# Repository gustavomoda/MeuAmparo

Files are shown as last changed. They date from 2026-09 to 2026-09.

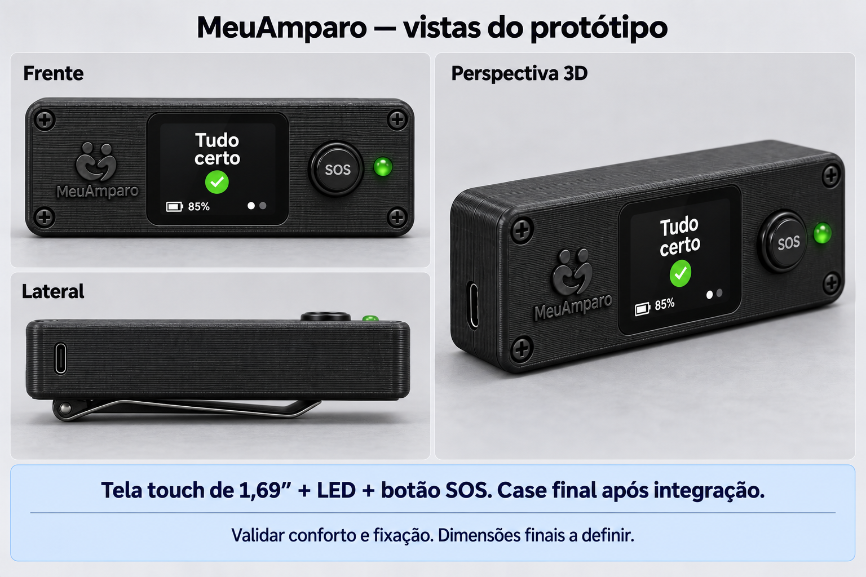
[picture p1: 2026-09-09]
docs/projeto/03-hardware/renders/touch_vistas.png

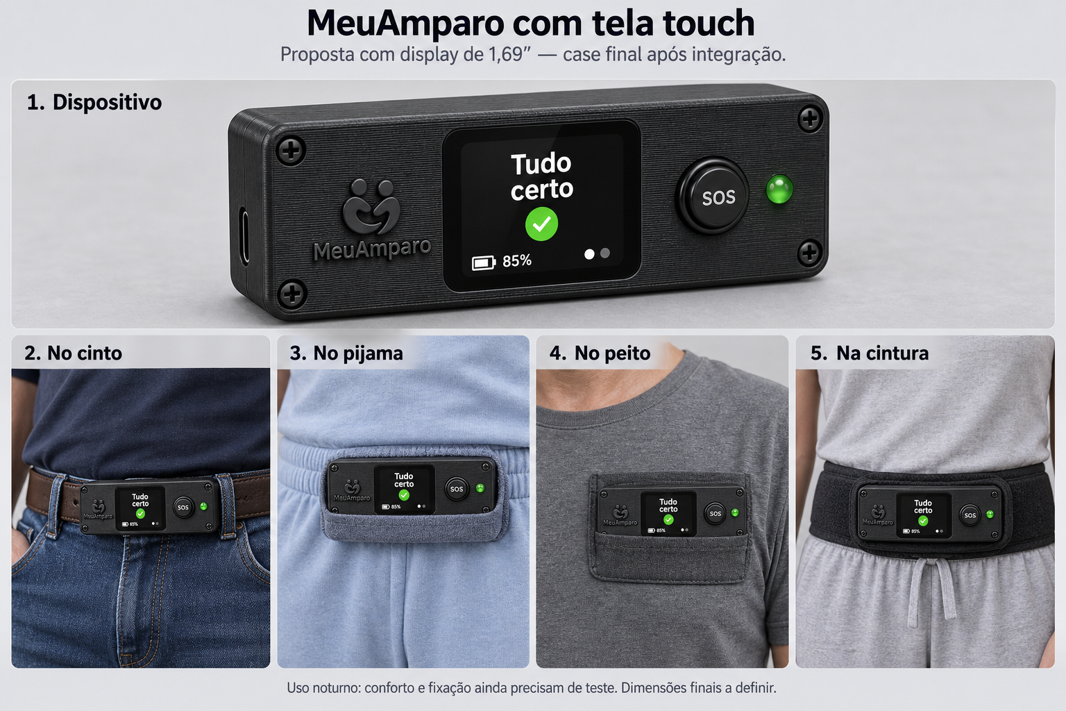
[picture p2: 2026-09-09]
docs/projeto/03-hardware/renders/touch_169_dispositivo_e_fixacoes.png

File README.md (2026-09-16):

MeuAmparo

# MeuAmparo

Dispositivo vestível de baixo custo para pessoas idosas: detecta queda, aceita pedido manual de
ajuda pelo botão e avisa o cuidador com a localização, inclusive quando a pessoa sai de uma área
segura.

Projeto de extensão da disciplina Programação de Microcontroladores (ARA4710), Estácio Ribeirão
Preto, semestre 2026.2. O desenvolvimento e os testes acontecem em simulação, no Wokwi, como o
roteiro da disciplina prevê; não haverá montagem física neste semestre.

O acompanhamento das tarefas fica no [quadro do projeto no GitHub](https://github.com/users/gustavomoda/projects/2):
cada entrega da disciplina é um marco, cada tarefa tem prazo, responsável e critério de pronto.

## Estado atual

Início do desenvolvimento, em 16/09/2026. O que existe hoje:

| Parte | Estado |
| --- | --- |
| Documentação da disciplina | Roteiro 1 entregue; Roteiro 2 em rascunho para 23/09; canvas apresentado |
| Instituição parceira | levantamento de 14 entidades; nenhuma contatada ainda |
| Hardware | case paramétrico em OpenSCAD, com STL de base e tampa, nunca conferido com a placa |
| Identidade visual | marca e ícone em PNG e SVG |
| `core/` | só a magnitude de aceleração, com teste de host passando |
| `firmware/` | projeto ESP-IDF mínimo, que pisca um LED |
| `simulator/` | diagrama Wokwi com ESP32-S3 e LED, rodando o firmware mínimo |
| Backend e painel | não iniciados |

Nada foi montado nem medido em placa física, e não vai ser neste semestre. Os números que aparecem
na documentação são metas e estimativas, não resultados.

## Estrutura

```text
docs/material-disciplina/   material recebido da Estácio, não editar
docs/projeto/               entregas, instituições, hardware e identidade visual (tem um README)
src/meuamparo/              código: core, firmware, simulador e testes
.agents/                    instruções para agentes de IA que trabalham no repositório
```

O código fica em `src/meuamparo/`, separado em quatro pastas com uma fronteira rígida:

```text
core/       algoritmos em C puro. Não sabe que ESP32 existe
firmware/   ESP-IDF. Só o que roda na placa
simulator/  Wokwi, custom chips e traces. Nada daqui vai para a placa
test/       testes de host, rodam sem ESP-IDF instalado
```

O motivo da separação está em [`src/meuamparo/README.md`](src/meuamparo/README.md). Resumindo: a meta
de detectar 90% das quedas só se mede rodando o algoritmo contra centenas de traces, e isso precisa
compilar em segundos no notebook, sem placa.

## Rodando

Os testes do core precisam só de um compilador C11. Firmware e simulação precisam do ESP-IDF e do
`wokwi-cli`, que o `make setup` instala.

```sh
cd src/meuamparo
make help      # lista os alvos
make test      # compila e roda os testes do core, sem ESP-IDF
make setup     # instala ESP-IDF e wokwi-cli, pulando o que já existe
make firmware  # compila o firmware (com o export.sh do ESP-IDF carregado)
make sim       # roda o firmware no Wokwi
```

## Arquitetura

A placa de referência é a Waveshare ESP32-S3-SIM7670G-4G, que junta o ESP32-S3, o modem 4G e o GNSS.
Em volta dela: sensor inercial MPU6050, bateria 18650, botão de pânico, buzzer e LED. Firmware em C
com ESP-IDF. Backend e painel web de alertas ainda sem stack definida.

A simulação no Wokwi cobre o ESP32-S3, o MPU6050, o botão, o buzzer e o LED. O 4G e o GNSS não
existem no simulador e serão representados de outra forma, por exemplo pelo Wi-Fi simulado.

## Metas

Detectar pelo menos 90% das quedas simuladas, menos de um alarme falso por dia, alerta de saída da
área segura em até dois minutos, autonomia mínima de oito horas, configuração independente em menos
de 15 minutos e avaliação da instituição parceira de pelo menos 4/5.

São critérios definidos no planejamento. Nenhum foi medido, e alguns (autonomia, alarmes falsos por
dia, configuração pela equipe) dependem de hardware que não vai existir neste semestre; a forma de
avaliá-los em simulação ainda está sendo decidida.

## Pendências

- **Simulador**: o Wokwi não é software livre, que é o que o roteiro da disciplina cita. Falta
  confirmar com o professor.
- **Documentos antigos**: o canvas e o Markdown de compras ainda citam a LilyGO T-A7670G R2, opção
  anterior à Waveshare, e as imagens conceituais em `docs/projeto/03-hardware/renders/` mostram uma
  tela touch que não faz parte do projeto.
- **Divisão do trabalho**: as frentes (instituição, firmware, backend, documentação) ainda não têm
  responsável nominal.
- **Instituição parceira**: em prospecção. Casa do Vovô, Lar Padre Euclides e Lar do Vovô Albano são
  as candidatas. Nenhuma parceria firmada.
- **Dataset de queda**: SisFall e FallAllD são os candidatos, licença e formato a conferir.

## Grupo

- Luis Gustavo Moda
- Isabelly Vitoria

Orientação: Prof. Omar Sacilotto Donaires.

## Licença

O código e os materiais autorais do MeuAmparo são disponibilizados sob a
[GNU General Public License, versão 3](LICENSE) (`GPL-3.0-only`).

Materiais da disciplina, dependências e outros conteúdos de terceiros mantêm suas próprias licenças.

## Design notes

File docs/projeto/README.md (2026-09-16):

# Documentos do MeuAmparo

Aqui fica tudo o que o grupo escreveu para a disciplina e para o projeto. O material que veio da
Estácio, como aulas, modelos e edital, está em [`docs/material-disciplina/`](../material-disciplina).
Se você ainda não sabe o que é o MeuAmparo, leia antes o [README principal](../../README.md).

## Se você só precisa da entrega

Os PDFs que vão para a SAVA ficam direto em `01-entregas/`, para quem só quer ler. A disciplina
aceita só PDF, um por grupo.

O texto dos roteiros é escrito em Markdown, em `md/`, e é dele que saem o Word e o PDF. A geração
automática ainda está sendo montada; até ela ficar pronta, quem mexer no Markdown precisa levar a
mudança para o `.docx` em `docx/`. Os Canvas são a exceção: eles seguem o modelo do professor e
continuam sendo editados direto no Word.

- Roteiro 1, diagnóstico e teorização: prazo em 09/09, PDF gerado.
- Roteiro 2, planejamento: prazo em 23/09, ainda em rascunho e sem PDF.
- Canvas do projeto e Canvas de apresentação: usados nos seminários. Só o de apresentação tem PDF.

## Datas que importam

| Data | O que acontece | Pontos |
| --- | --- | --- |
| 09/set | Entrega do diagnóstico e teorização | 2,0 |
| 16/set | Seminário de planejamento | — |
| 21/set | Prazo de submissão do III EPEI | — |
| 23/set | Entrega do planejamento | 1,0 |
| 28/out | Seminário de desenvolvimento | — |
| 25/nov | Entrega final e seminário de avaliação | 7,0 |

Para passar, a nota precisa ser 6,0 ou mais, com pelo menos 75% de frequência. Essas datas são as
do calendário atualizado na Aula 04. O Canvas ainda mostra as da Aula 01, que foram adiadas: o
diagnóstico era 02/09 e o seminário de desenvolvimento, 21/10.

## Onde está cada coisa

```text
01-entregas/            os PDFs entregues na SAVA
  md/                   texto dos roteiros, a fonte de onde sai o resto
  docx/                 versão em Word
  figuras/              imagens usadas nas entregas, como o Gantt
02-parte-interessada/   14 instituições de Ribeirão Preto e o Conselho do Idoso, com roteiro de ligação
03-hardware/            cotação, projeto do case e onde usar o dispositivo no corpo
  case/                 modelo em OpenSCAD e os STL da base e da tampa
  renders/              imagens conceituais do case e das formas de prender
04-identidade-visual/   marca e ícone, em PNG e SVG
```

Nas pastas 02 e 03, o `.docx` e o `.md` de um mesmo documento ainda ficam lado a lado e não se
atualizam sozinhos. Quem mexer em um precisa levar a mudança para o outro, senão os dois começam a
contar histórias diferentes, o que já aconteceu neste projeto.

As imagens de `03-hardware/renders/` são estudos de aparência. Algumas mostram uma tela touch que
não faz parte da arquitetura nem da cotação.

## O que ainda não está resolvido

A instituição parceira ainda não existe. Casa do Vovô, Lar Padre Euclides e Lar do Vovô Albano são
as candidatas mais fortes, mas até agora nenhuma foi visitada e nenhum acordo foi fechado. O
planejamento depende dessa conversa: sem ela, não há como dizer como a equipe da instituição vai
participar.

A placa de referência é a Waveshare ESP32-S3-SIM7670G. Ela usa o mesmo chip, o ESP32-S3, que o
código e o simulador já usam, e o case foi desenhado para ela. Só que ela não vai ser comprada neste
semestre: não dá tempo de receber, montar e testar até novembro. Uma unidade completa custaria entre
R$ 597 e R$ 622, pela estimativa de setembro de 2026. O case partiu das medidas do catálogo e nunca
foi conferido com a placa. Parte dos documentos ainda cita a LilyGO T-A7670G R2, a opção anterior.

Pelo roteiro da disciplina, o sistema é desenvolvido e testado em simulação, e a montagem física só
entra se houver recursos. Aqui ela não vai entrar: todo o desenvolvimento e os testes são no Wokwi. Só que o roteiro pede software livre, e
o Wokwi não é; essa escolha ainda precisa ser justificada ou combinada com o professor.

O cronograma divide o trabalho por frente (instituição, hardware, firmware e documentação), mas
ainda não diz quem cuida de cada uma.

E vale lembrar que nada foi montado nem medido até agora. Números como os 90% de detecção de queda
são metas, não resultados.

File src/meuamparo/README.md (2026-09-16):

# MeuAmparo — firmware e simulador

Dispositivo vestível de baixo custo para pessoas idosas: detecta queda, aceita pedido manual de
ajuda pelo botão e avisa o cuidador com a localização, inclusive quando a pessoa sai de uma área
segura.

Disciplina Programação de Microcontroladores (ARA4710), Estácio Ribeirão Preto, 2026.2.
Grupo: Luis Gustavo Moda e Isabelly Vitoria. Orientação: Prof. Omar Sacilotto Donaires.

## Estrutura

```
core/         algoritmos em C puro. Não sabe que ESP32 existe.
firmware/     ESP-IDF. Só entra aqui o que roda na placa física.
simulator/    Wokwi, custom chips, traces e ferramentas. Nada daqui vai para a placa.
test/         testes de host do core, rodam no Mac sem ESP-IDF instalado.
```

A fronteira entre as três pastas é a regra mais importante do repositório. `core/` não inclui
nenhum header do ESP-IDF. `firmware/` não contém trace, mock nem cenário. `simulator/` pode
depender de qualquer coisa, porque não vai para produção.

## Como rodar

```
make setup      instala ESP-IDF e wokwi-cli, pulando o que já existe
make test       compila e roda os testes de host do core
make firmware   compila o firmware ESP-IDF
make sim        roda a demo no Wokwi headless sobre o binário compilado
make clean      apaga build/ e firmware/build/
```

`make test` não depende de nada disso. Precisa de um compilador C11 e mais nada, que é o motivo
de ele rodar igual no Mac, no Windows do laboratório e num CI sem toolchain de embarcado.

Os outros alvos precisam do ESP-IDF. `make setup` clona a v5.5.5 em `~/esp/esp-idf`, instala a
toolchain do esp32s3 em `~/.espressif` e o `wokwi-cli` pelo npm. Cada etapa confere antes de
baixar, então repetir o comando custa segundos em vez de vários GB. Serve para conferir uma
máquina nova sem medo de refazer download.

Feito o setup, falta carregar o ambiente na shell uma vez por sessão:

```
. ~/esp/esp-idf/export.sh
export WOKWI_CLI_TOKEN=...   # token de CI, em https://wokwi.com/dashboard/ci
```

`make sim` compila antes de rodar e falha se a linha `led=1` não aparecer no serial em 10
segundos. O LED piscando no navegador é o que se vê na apresentação; o critério de verificação
é essa linha no log.

## A demo do LED

`firmware/main/main.c` pisca o GPIO2 a cada meio segundo e imprime o estado. Não lê sensor, não
chama o `core/` e não envia alerta nenhum. Existe para fechar a cadeia do passo 4 antes de haver
lógica dentro dela: o ESP-IDF compila, o binário sobe no Wokwi, o pino responde. Quando o detector
de queda entrar, esse LED vira o indicador de alerta.

O circuito fica em `simulator/wokwi/diagram.json`: devkit ESP32-S3, LED e resistor de 330 Ω.

## Por que separar assim

A meta documentada é detectar pelo menos 90% das quedas simuladas com menos de um alarme falso
por dia. Isso não se mede apertando botão no simulador: mede-se rodando o algoritmo contra
centenas de traces de acelerômetro e contando acertos. Para isso o algoritmo precisa compilar no
Mac, em segundos, sem placa e sem toolchain de embarcado. Daí o `core/`.

O firmware fica fino de propósito: lê o MPU6050, lê o GNSS, chama o core, obedece ao que o core
decidir. Se a lógica de queda vivesse dentro de uma task do FreeRTOS, cada ajuste de limiar
custaria um ciclo de compilar, gravar e derrubar o protótipo de novo.

## Decisões, e por quê

### PICSimLab ficou de fora

PICSimLab simula PIC16/18, AVR e STM32. Não simula ESP32, então não roda uma linha do firmware
deste projeto. Também não tem peça para MPU6050, GNSS ou modem: sensor de queda e GPS virariam
texto digitado num terminal virtual.

Ele aparece na Aula 04 como leitura do Módulo 2 do conteúdo digital, junto com MPLAB e CCS C. É
bibliografia da disciplina, não exigência do projeto. A Aula 03 lista o ESP32 entre as famílias
de microcontrolador estudadas, ao lado de PIC, AVR e ARM.

### Wokwi como bancada visual

O Wokwi roda o binário do ESP-IDF de verdade, não uma reimplementação. Tem ESP32-S3, MPU6050,
botão, LED e buzzer como peças prontas. Roda no navegador, o que resolve Mac, Windows e a máquina
do laboratório com a mesma URL e nenhuma instalação. A extensão do VS Code roda local nos dois
sistemas, mas pede chave de licença.

### O modem 4G não é simulado. O transporte é trocado

Nenhum simulador tem modelo de SIM7670 ou A7670. Em vez de escrever um chip falso que responde
comandos AT, o firmware conversa com uma interface de transporte que tem duas implementações: no
Wokwi sai pelo Wi-Fi virtual, que dá internet real ao ESP32 simulado; na placa sai pelo modem.
O backend recebe a mesma requisição nos dois casos e não precisa saber a diferença.

Isso troca um custom chip complicado por uma interface de três funções. O preço é honesto: o
caminho do modem continua sem cobertura de teste até a placa chegar.

### GNSS precisa de custom chip

Aqui não tem atalho. O Wokwi não tem GPS na biblioteca, então o jeito é escrever um custom chip
que cospe sentenças NMEA de uma rota gravada. É o que permite a demo rodar sozinha: a pessoa
caminha, sai da área segura, o alerta dispara sem ninguém arrastar slider.

### O que simulador nenhum prova

Autonomia de oito horas só sai medindo a placa com a bateria real. Conforto e fixação dependem
das pessoas da instituição parceira. Alarme falso em uso cotidiano depende de rotina real, não de
trace de laboratório. O simulador cobre lógica e demonstração, e é isso.

## Plano

Cada passo tem um critério de verificação. Passo sem critério verificável não conta como pronto.

1. Esqueleto e `core/` compilando isolado. Verifica: `make test` passa no Mac, sem ESP-IDF.
2. Detector de queda e replayer de trace. Verifica: taxa de detecção e falsos positivos impressos
   como número, medidos contra dataset público.
3. Geofence e máquina de estados. Verifica: teste dispara alerta ao cruzar o raio, e uma vez só.
4. Firmware ESP-IDF com transporte Wi-Fi. Verifica: compila, sobe no Wokwi, alerta sai no log.
5. Custom chips do simulador (GNSS e replay do MPU). Verifica: cenário roda do play até o alerta
   sem interação, com LED e buzzer disparando.
6. Backend mínimo e painel com mapa. Verifica: alerta saído do Wokwi aparece no painel.
7. Seeder de dados sintéticos. Verifica: painel com histórico e vários dispositivos.
8. Documentos da disciplina. Verifica: coerência entre Word, Markdown e Canvas.

## Pendências

- A placa é a Waveshare ESP32-S3-SIM7670G. O Wokwi não tem peça para o modem 4G nem para o GNSS,
  então essas partes precisam ser representadas de outro jeito na simulação.
- Dataset de queda: SisFall e FallAllD são os candidatos. Conferir licença e formato antes de usar.
- Licença do Wokwi para a extensão do VS Code. A versão web resolve a apresentação.

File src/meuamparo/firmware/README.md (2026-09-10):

# firmware

Só entra aqui código que roda no ESP32-S3. Se não vai para a placa, o lugar é `../simulator/`.

Responsabilidade: ler o MPU6050 por I2C, ler o GNSS por UART, alimentar o `core/` com esses dados
e executar o que o core decidir (acender LED, tocar buzzer, enviar alerta). A lógica de queda e de
área segura não mora aqui, mora em `../core/`.

O envio do alerta passa por uma interface de transporte com duas implementações: Wi-Fi, usada no
Wokwi, e modem 4G, usada na placa. O resto do firmware não sabe qual das duas está ativa.

Nenhum trace, mock ou cenário de teste entra nesta pasta.

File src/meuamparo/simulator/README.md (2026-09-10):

# simulator

Nada aqui roda na placa. É a bancada de simulação e demonstração.

```
wokwi/    diagram.json e wokwi.toml: o circuito que aparece na tela
chips/    custom chips do Wokwi. GNSS emitindo NMEA, MPU6050 reproduzindo trace gravado
traces/   datasets de queda e de atividade normal
tools/    replayer, gerador de cenário e seeder do painel
```

O Wokwi roda o binário real gerado por `../firmware/`. Os custom chips existem porque o Wokwi não
tem GPS nem modem na biblioteca de peças, e porque o MPU6050 nativo só responde a slider — não
reproduz uma queda gravada.

O objetivo do cenário automático é a demo rodar do play até o alerta chegar no painel, sem ninguém
mexer em nada durante a apresentação.

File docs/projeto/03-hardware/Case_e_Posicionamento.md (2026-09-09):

# MeuAmparo — Case do dispositivo e posicionamento no corpo

Projeto do invólucro para impressão terceirizada e protocolo de teste de posicionamento
Setembro de 2026

---

## 1. Dimensões do case

O modelo foi construído a partir da placa **Waveshare ESP32-S3-SIM7670G-4G**, cujo datasheet informa **110 × 30,44 mm**.

| | Medida |
|---|---|
| Placa | 110,00 × 30,44 × 1,60 mm |
| Suporte da bateria 18650 sobre a placa | 19,50 mm *(a medir)* |
| Componentes sob a placa | 3,00 mm *(a medir)* |
| Folga interna | 1,50 mm por lado |
| Espessura de parede | 2,20 mm |
| **Case fechado** | **117,4 × 37,8 × 30,0 mm** |
| Peso estimado do conjunto | 100 a 115 g |

Para comparação: um cartão de crédito tem 85,6 × 54 mm. O dispositivo é mais comprido e bem mais estreito — o formato lembra um crachá de congresso ou um controle de portão grande.

O case é dividido em **base** (bandeja que abriga a placa, com o recorte do USB e os furos do buzzer) e **tampa** (com o botão, os LEDs e a janela da antena), unidas por quatro parafusos M2 auto-atarraxantes nos cantos e por um lábio de encaixe que alinha as duas peças.

---

## 2. Onde fica cada coisa

Todas as posições são medidas **a partir da borda esquerda da placa**, no sentido do comprimento. Cada uma é um parâmetro no arquivo `.scad` e muda numa linha.

### Face superior (tampa)

| Elemento | Diâmetro / tamanho | Posição | Função |
|---|---|---|---|
| **Botão de pânico** | Ø 12 mm | 30 mm | Acionamento manual e cancelamento do alarme falso. Grande e saliente de propósito: mão com artrose não acha botão pequeno, e no escuro tem que dar para achar pelo tato |
| **LED RGB do projeto** | Ø 5,2 mm | 15 mm | Estado do dispositivo, visível para o cuidador. Verde ligado, âmbar sem rede, vermelho piscando em alerta |
| **Janela dos LEDs da placa** | 22 × 7 mm, parede de 0,8 mm | 22 mm *(a medir)* | Deixa ver os LEDs de fábrica sem furar. Impressa em 0,8 mm o PETG fica translúcido |
| **Janela da antena GNSS** | 26 × 26 mm, parede de 1,2 mm | 92 mm *(a medir)* | **Crítico.** A antena cerâmica precisa "ver" o céu. Parede fina, nada de metal por cima, e essa face sempre voltada para fora do corpo |

Os LEDs de fábrica da placa, segundo a documentação da Waveshare, são: **azul** para energia, **verde** para carregamento solar, **vermelho piscando** para status da rede e **amarelo** para advertência de bateria invertida. Nenhum deles é informação para o idoso — são para quem monta e diagnostica. Por isso ficam atrás de uma janela translúcida, e não de um furo.

### Face inferior (base)

| Elemento | Detalhe | Posição |
|---|---|---|
| **Furos do buzzer** | Matriz 3 × 3 de Ø 2,2 mm, espaçados 4,5 mm | 62 mm, centralizado na largura |
| **Rebaixo do clipe de cinto** | 30 × 18 × 1,2 mm, com dois furos M3 a 18 mm um do outro | centro |

Os furos do buzzer ficam voltados para baixo para não acumular água, e o som ainda atravessa a roupa.

### Lateral esquerda

| Elemento | Detalhe |
|---|---|
| **Recorte do USB-C** | 9,5 × 4,2 mm, centralizado na largura, alinhado ao conector |

A carga é diária, então o conector precisa ser acessível sem abrir o case.

### Topo (lateral direita)

Dois ilhoses de Ø 4,5 mm, afastados 14 mm um do outro, para o cordão de pescoço. O cordão deve ser **largo e macio**: com 100 g pendurados, fio fino de 3 mm serra o pescoço.

**Segurança:** o cordão precisa ser do tipo *breakaway*, que se solta sob tração. É requisito de segurança, não conforto — cordão fixo em pescoço de idoso é risco de estrangulamento.

---

## 3. O que medir quando a placa chegar

O modelo é paramétrico. Ao receber a placa, meça estes sete valores com paquímetro e altere as linhas correspondentes no arquivo `.scad`. Nada mais precisa mudar.

| Parâmetro no arquivo | O que medir |
|---|---|
| `alt_sup_18650` | Altura do suporte da bateria, do topo da placa até o ponto mais alto |
| `alt_inferior` | Altura dos componentes soldados na face de baixo da placa |
| `pos_usb` | Distância da borda esquerda até o centro do conector USB-C |
| `pos_leds_placa` | Distância da borda esquerda até o centro do grupo de LEDs |
| `pos_antena_gnss` | Distância da borda esquerda até o centro da antena cerâmica |
| `usb_larg` e `usb_alt` | Largura e altura do corpo do conector USB-C |
| `pcb_comp` e `pcb_larg` | Confirmar os 110 × 30,44 mm do datasheet |

Só depois dessa conferência os arquivos devem ir para a impressão. Imprimir antes de medir é jogar dinheiro fora.

---

## 4. Especificação de impressão

| Parâmetro | Valor | Por quê |
|---|---|---|
| Material | **PETG** | O PLA amolece a 60 °C e deforma no painel do carro ou ao sol. O PETG aguenta e é menos quebradiço. Custa quase o mesmo |
| Cor | Clara, ou natural translúcido | Absorve menos calor e deixa as janelas de LED funcionarem |
| Altura de camada | 0,20 mm | Suficiente; 0,12 mm só deixa mais lento |
| Perímetros | 3 | Define a resistência real da parede de 2,2 mm |
| Preenchimento | 25%, giroide | Rigidez suficiente sem peso extra |
| Suportes | Não | O modelo foi desenhado sem balanços que exijam suporte |
| Orientação | Ambas as peças com a face aberta para cima | Melhor acabamento nas faces visíveis |

**Custo do serviço terceirizado:** de R$ 40 a R$ 60 por conjunto de duas peças. Você envia os arquivos `meuamparo_case_base.stl` e `meuamparo_case_tampa.stl`, e recebe pronto. Não é preciso ter a máquina.

**Ferragens a comprar à parte:** 4 parafusos M2 × 8 mm auto-atarraxantes (tampa), 2 parafusos M3 × 6 mm (clipe de cinto), 1 clipe de cinto metálico, 1 cordão breakaway.

---

## 5. Alternativa sem impressão

A placa Waveshare **já vem com estojo acrílico transparente e parafusos** no pacote. Ele protege a eletrônica, mas não prende no corpo.

Para vestir sem fabricar nada: **porta-celular de neoprene com passador de cinto e ilhó para cordão**, de R$ 20 a R$ 35 em qualquer marketplace. Um modelo para celular grande engole os 117 × 38 mm com folga, e a dupla fixação resolve as duas posições — cinto de dia, pescoço à noite.

**Isso deve constar da documentação do kit como opção padrão.** Uma ONG também não tem impressora 3D, e exigir uma peça impressa cria uma barreira de replicação que o projeto não precisa ter. O case impresso entra como melhoria opcional, não como requisito.

---

## 6. Posicionamento no corpo — as opções a testar

O pulso está descartado por um motivo simples: com 117 mm de comprimento, o dispositivo não cabe. Restam três posições viáveis, e a decisão entre elas deve sair de teste, não de opinião.

| Posição | Qualidade esperada do sinal | Conforto | Cobertura 24h | Como fixar |
|---|---|---|---|---|
| **A — Cintura, no cinto** | **Melhor.** Fica sobre o centro de massa, que é onde os conjuntos de dados de referência posicionam o sensor | Boa, discreta sob a roupa | Falha à noite: de pijama não há cinto | Clipe de cinto ou porta-celular com passador |
| **B — Peito, no cordão** | Muito boa | Sente-se o peso; exige cordão largo | Funciona sempre, inclusive dormindo | Cordão breakaway, curto o bastante para o aparelho encostar no corpo |
| **C — Braço, na braçadeira** | Média. O braço tem aceleração própria e gera mais alarme falso | Razoável de dia | Incômodo para dormir | Braçadeira de corrida para celular, R$ 25 a R$ 40 |

**Detalhe que quase todo projeto erra:** na posição B, o cordão precisa ser curto o suficiente para o dispositivo **encostar no peito**. Solto, ele balança, e o acelerômetro lê o balanço como movimento — o algoritmo enche de falso positivo. Regule para o aparelho ficar cerca de 15 cm abaixo do queixo.

---

## 7. Protocolo de teste de posicionamento

Executar assim que o firmware detectar queda, antes de qualquer teste com a instituição.

### Regras de segurança

Os testes de queda são feitos por **voluntários adultos e saudáveis do próprio grupo**, sobre colchonete, nunca por pessoas idosas. Nenhuma queda é simulada por participante do projeto de extensão.

### Sequência, repetida nas três posições

**Bloco 1 — Quedas que devem ser detectadas** (5 repetições de cada):

1. Queda para a frente, com apoio dos braços
2. Queda para a frente, sem apoio
3. Queda lateral, para a direita
4. Queda lateral, para a esquerda
5. Queda para trás, sentando e caindo
6. Escorregão com queda lenta, deslizando pela parede

**Bloco 2 — Atividades que NÃO podem disparar alarme** (5 repetições de cada):

1. Sentar-se bruscamente numa cadeira
2. Deitar-se rapidamente na cama
3. Levantar-se da cadeira
4. Caminhar 20 passos
5. Subir e descer cinco degraus
6. Agachar para pegar um objeto no chão
7. Tirar o dispositivo e apoiá-lo na mesa

### O que registrar

| Métrica | Como calcular | Meta |
|---|---|---|
| **Sensibilidade** | quedas detectadas ÷ 30 quedas do bloco 1 | ≥ 90% |
| **Alarmes falsos** | disparos no bloco 2 ÷ 35 atividades | ≤ 5% |
| **Tempo até o alerta** | do impacto ao envio, em segundos | ≤ 45 s, contando a janela de cancelamento |
| **Conforto** | nota de 1 a 5 dada pelo voluntário após 2 h de uso | ≥ 4 |

Registrar em planilha, uma linha por tentativa, com posição, tipo de movimento, se detectou e observação. Filmar ao menos uma repetição de cada tipo: além de servir de evidência obrigatória para o roteiro de extensão, o vídeo ajuda a entender por que uma detecção falhou.

### Decisão

A posição escolhida é a que atinge as metas de sensibilidade e alarme falso com a maior nota de conforto. Se duas posições empatarem no sinal, **vence a de melhor conforto** — porque dispositivo que incomoda não é usado, e dispositivo na gaveta tem sensibilidade zero.

Se a cintura vencer no sinal mas perder na cobertura noturna, a resposta não é escolher uma: é entregar o dispositivo com as duas fixações e orientar o uso no cinto durante o dia e no pescoço à noite.

---

## Arquivos

| Arquivo | Conteúdo |
|---|---|
| `meuamparo_case.scad` | Modelo paramétrico em OpenSCAD, com todos os parâmetros comentados |
| `meuamparo_case_base.stl` | Base, pronta para impressão |
| `meuamparo_case_tampa.stl` | Tampa, pronta para impressão |
| `case_conjunto.png` | Vista das duas peças |
| `case_tampa.png` | Vista da tampa |

O OpenSCAD é software livre e o modelo é código-fonte, o que permite versioná-lo no mesmo repositório do firmware. Para gerar os STL depois de ajustar as medidas:

```
openscad -o meuamparo_case_base.stl  -D peca=1 meuamparo_case.scad
openscad -o meuamparo_case_tampa.stl -D peca=2 meuamparo_case.scad
```

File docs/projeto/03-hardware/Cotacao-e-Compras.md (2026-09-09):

# MeuAmparo — Cotação e estratégia de compra

Levantamento feito em setembro de 2026. Preços mudam; confirme antes de fechar.

---

## 1. A regra de importação mudou a favor do projeto

Desde **12 e 13 de maio de 2026**, a Medida Provisória nº 1.357 **zerou o Imposto de Importação federal para compras internacionais de até US$ 50**, quando feitas em sites certificados no Programa Remessa Conforme (AliExpress e Amazon internacional estão no programa).

| Faixa | Imposto federal | ICMS |
|---|---|---|
| Até US$ 50 | **0%** | 17% a 20% conforme o estado (SP: 18%) |
| Acima de US$ 50 | 30% a 60%, conforme a fonte | 17% a 20% |

A placa que interessa custa entre **US$ 32 e US$ 38**. Fica abaixo do limite, então paga só ICMS. É por isso que importar continua valendo a pena mesmo com o frete.

**Regra prática:** faça pedidos separados, cada um abaixo de US$ 50. Dois itens somando US$ 60 num pedido só entram na faixa cara. Separados, os dois ficam isentos do federal.

> A Receita tem uma calculadora oficial no portal de Compras Internacionais. Use antes de fechar, porque a alíquota estadual e o frete entram na conta.

---

## 2. A estratégia: dividir a compra em dois

O erro clássico é comprar tudo no mesmo lugar. Nenhum canal ganha em tudo.

**Importe da China só a placa 4G/GPS.** É o item caro, é o que não tem equivalente nacional a preço aceitável, e é o único que justifica esperar.

**Compre no Brasil todo o resto.** Sensor, bateria, botão, buzzer, fios: são baratos, chegam em dias, e o frete nacional é menor que a dor de cabeça de esperar.

---

## 3. Comparação dos canais

| | AliExpress (China) | Mercado Livre | Amazon BR | Lojas maker nacionais |
|---|---|---|---|---|
| Preço da placa 4G/GPS | **US$ 32-38** (~R$ 230-270 com ICMS e frete) | R$ 250-400, revenda de importado | pouca oferta de maker | **R$ 590 a R$ 719** |
| Prazo | 20 a 45 dias | 3 a 10 dias | 2 a 7 dias | 3 a 10 dias |
| Nota fiscal | não | sim | sim | sim |
| Garantia na prática | nenhuma | ML te cobre | Amazon te cobre | sim, com suporte |
| Risco de variante errada | **alto** | alto | médio | baixo |
| Componentes pequenos | baratos, mas prazo longo | bom preço e prazo | caro | **melhor opção** |

**Lojas maker nacionais que valem consulta:** Curto Circuito, Eletrogate, Smart Kits, Usinainfo, Baú da Eletrônica, Robocore, Autocore Robótica.

---

## 4. Lista de compras, por canal

### Importar (AliExpress) — pedir hoje

| Item | Especificação exata | Preço |
|---|---|---|
| Placa principal | **LilyGO T-A7670G R2, variante G ou SA, opção COM GPS** | US$ 32-38 |

Já vem com antena 4G, antena GPS, cabo PH2.0, barras de pinos e o conversor USB CH9102F.

### Comprar no Brasil — chega em dias

| Item | Onde | Preço de referência |
|---|---|---|
| MPU6050 (acelerômetro e giroscópio) | Curto Circuito, Eletrogate, ML | R$ 28 |
| Bateria 18650 3500 mAh, marca genuína | ML, lojas de bateria | R$ 45-70 |
| Botão táctil 12 mm, buzzer 5 V, LED RGB | qualquer loja maker | R$ 15 |
| Barras de pinos, jumpers, parafusos M2 | qualquer loja maker | R$ 10 |
| Filamento PETG para o case | ML | R$ 15 (fração do rolo) |
| Cordão com engate de segurança | papelaria, ML | R$ 15 |

### Depois, se o projeto avançar

- Placa portadora, lote de 5 na JLCPCB: cerca de R$ 12 por unidade
- Chip M2M de dados: Arqia, Allcom ou Vivo M2M

---

## 5. Cuidados que evitam prejuízo

**A variante do módulo.** Peça **A7670G** (global) ou **A7670SA** (América do Sul). O **A7670E é europeu** e vai ter cobertura ruim nas bandas brasileiras, principalmente a B28 de 700 MHz, que é a que pega no interior. Mande mensagem ao vendedor confirmando a variante antes de pagar, e guarde o print.

**A opção com GPS.** A mesma placa é vendida com e sem GPS, muitas vezes no mesmo anúncio, com o mesmo preço na vitrine. Confira o seletor antes de finalizar.

**Bateria 18650 falsificada.** Anúncio de 9900 mAh por R$ 15 é mentira: a maior 18650 real do mercado tem cerca de 3600 mAh. Compre Samsung, LG ou Sony de vendedor com reputação, ou a autonomia do projeto vira ficção.

**Disponibilidade nacional é instável.** No levantamento, dois dos três itens que consultei em loja nacional estavam esgotados. Para um kit que ONGs vão replicar, isso precisa constar da documentação com fornecedor alternativo indicado.

**Compre duas placas.** Uma queima na bancada, uma trava na alfândega, e você fica sem protótipo na semana da entrega. A segunda unidade custa menos que o risco.

---

## 6. Prazo, contado de hoje

Pedido feito em **09/set** chega entre **29/set e 24/out**. A entrega final do detalhamento técnico é **25/nov**. Cabe, com folga de três a oito semanas.

E há uma rede de segurança: o Roteiro de Extensão aceita **desenvolvimento e teste por simulação computacional** em software livre, citando o SimulIDE. A montagem física aparece como "eventualmente, se houver recursos disponíveis". Se a placa atrasar ou não chegar, a entrega não cai — o protótipo físico é bônus, não requisito.

---

## Fontes

- Receita Federal — Remessas postal e expressa, regras vigentes desde 12/05/2026
- Contábeis — fim da taxa das blusinhas, compras até US$ 50 isentas de imposto federal
- Curto Circuito — módulo SIM7600G 4G LTE GPS, R$ 719
- Curto Circuito — MPU6050, R$ 28,10
- Smart Kits — LilyGO T-SIM7000G, R$ 589,90
- Importe Eletrônicos — LilyGO T-A7670G/E/SA R2, R$ 169
- Bot'n Roll — T-A7670G R2 com GPS L76K, € 55,50 (referência europeia)

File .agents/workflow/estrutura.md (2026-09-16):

# Estrutura do repositório

Duas metades com propósitos diferentes: `docs/` guarda o que é entregue para a faculdade,
`src/` guarda o que roda. Não misture. Documento não entra em `src/`, código não
entra em `docs/`.

```
.agents/workflow/   estas instruções. AGENTS.md e CLAUDE.md são só ponteiros para o index.md
docs/               material da disciplina e documentos do projeto
src/meuamparo/      código: core, firmware, simulador e testes
```

## docs/

```
docs/material-disciplina/   PDFs e modelos da disciplina. Material recebido, não editar
docs/projeto/               tudo que o grupo produz
```

`material-disciplina/` tem as aulas 01 a 05, o roteiro de extensão, a carta de apresentação, o
Canvas oficial em docx e pdf, e o edital do III EPEI. É a fonte para modelo, formatação e
calendário. Consulte antes de redigir qualquer entrega, e não presuma a regra de formatação.

`projeto/` tem um `README.md` que serve de índice e mantém a organização numerada:

```
01-entregas/            os PDFs entregues na SAVA ficam na raiz da pasta
  md/                   Markdown dos roteiros: a fonte da verdade
  docx/                 Word gerado a partir do Markdown (e os Canvas, editados no Word)
  figuras/              imagens usadas nas entregas, como o Gantt do cronograma
02-parte-interessada/   levantamento de instituições de Ribeirão Preto
03-hardware/            cotação, case e posicionamento
  case/                 scad e os dois stl
  renders/              imagens conceituais do case e das fixações
04-identidade-visual/   logos/ e icones/, em PNG de 512 a 6000 px e em SVG
```

Nos roteiros, o `.md` é a fonte da verdade e o `.docx` e o `.pdf` são gerados a partir dele. Enquanto
a geração automática não existe, qualquer mudança no `.md` precisa ser levada ao `.docx`. Os Canvas
seguem o modelo do professor e continuam editados no Word.

O resumo do III EPEI, se for submetido, é outra saída: texto puro de 2.000 a 5.000 caracteres sem
espaços, sem tabela, figura, autoria nem referências, nas seções exigidas pelo edital
(`docs/material-disciplina/Edital_III_EPEI.pdf`). O EPEI não define formatação de docx ou pdf. Nas
pastas 02 e 03 o `.docx` e o `.md` do mesmo documento ficam lado a lado. Nenhum par sincroniza sozinho: editou um, confira o outro antes de
dizer que está pronto.

Prefira o SVG da identidade visual quando o destino aceitar.

Arquivos que começam com `~$` são lock temporário do Word. Ignore, não versione, não trate como
conteúdo.

## src/meuamparo/

```
core/        algoritmos em C puro. Não sabe que ESP32 existe
firmware/    ESP-IDF. Só o que roda na placa física
simulator/   Wokwi, custom chips, traces e ferramentas. Nada daqui vai para a placa
test/        testes de host do core, rodam no Mac sem ESP-IDF instalado
build/       saída do make, fora do git
Makefile     alvos help, test e clean
```

Hoje só `core/` e `test/` têm conteúdo: um `imu.c` de oito linhas e um teste que passa.
`firmware/main`, `firmware/components` e as quatro pastas de `simulator/` estão vazias. Os README
de cada pasta descrevem o destino, não o estado atual — não leia como se já existisse.

O detalhe de cada camada, e o motivo da separação, está em `src/meuamparo/README.md` e nos README de
`core/`, `firmware/` e `simulator/`. Esses arquivos são a fonte; não duplique o conteúdo deles aqui.

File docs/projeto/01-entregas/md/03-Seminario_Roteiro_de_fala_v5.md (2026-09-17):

# MeuAmparo — roteiro de fala

## 1. MeuAmparo

Abertura: o projeto pretende identificar possíveis quedas, permitir pedidos de ajuda e avisar cuidadores com a localização. Hoje apresentamos o planejamento. A instituição ainda está em prospecção.

## 2. Todas as fases, com evidências

Vamos ouvir a instituição, definir requisitos, projetar e desenvolver a solução, testar e avaliar. Estudos técnicos podem avançar durante a prospecção. As atividades com o público dependem do aceite. Cada fase gera evidências: registros, requisitos, código, testes e avaliação.

## 3. Marcos até novembro

Calendário atualizado da Aula 04: planejamento em 23/09, seminário de desenvolvimento em 28/10 e entrega final com seminário de avaliação em 25/11. Proposta de sequência: requisitos e validação, implementação e testes, avaliação e relatos.

## 4. C com ESP-IDF e uma pequena PoC

Usaremos C com ESP-IDF. ESP-IDF é o framework oficial da Espressif: reúne ferramentas, drivers e bibliotecas para programar a família ESP32. Ele aceita C e C++. C++ oferece classes e outros recursos úteis para organizar interfaces e componentes, mas não torna o detector automaticamente mais preciso ou mais rápido. C já atende ao cálculo e mantém continuidade com a PoC atual. Podemos avaliar C++ se a complexidade da interface touch justificar; ainda não é uma mudança definida. Fonte: https://docs.espressif.com/projects/esp-idf/en/stable/esp32/api-guides/cplusplus.html . Core contém a lógica independente de hardware; firmware executa no ESP32; simulator reúne circuitos e cenários; test executa a lógica no computador. A pequena PoC já reúne magnitude da aceleração com teste de host e LED no ESP32-S3 simulado. Ela não implementa o detector completo nem o painel. Captura da estrutura fornecida pelo grupo.

## 5. Quem pensamos em envolver

Pessoas idosas são as beneficiárias. Cuidadores e familiares são destinatários dos alertas. A coordenação da instituição ajuda a definir a rotina e a viabilizar a participação. Casa do Vovô, Lar Padre Euclides e Lar do Vovô Albano são candidatas, não parceiras confirmadas.

## 6. Como vamos iniciar o contato

Estratégia proposta: telefonar à coordenação, apresentar o projeto de extensão e pedir uma conversa. Levar a carta de apresentação e um resumo visual. Ouvir necessidades antes de fechar requisitos. Se houver interesse, combinar a participação e registrar o aceite. Durante o desenvolvimento, validar fluxo e interface. Ao final, demonstrar a simulação e recolher feedback, com registros autorizados. Não provocar quedas em pessoas.

## 7. Frentes de trabalho

Proposta de distribuição ainda a confirmar: Gustavo na implementação técnica; Isa na organização de requisitos, registros e preparação da avaliação. Ambos participam do contato, testes e revisão. A distribuição será registrada e ajustada à disponibilidade e ao aprendizado. Não apresentar essas frentes como atividades individuais já realizadas.

## 8. GitHub Projects e Kanban

Vamos organizar as tarefas no GitHub Projects: https://github.com/users/gustavomoda/projects/2/views/4 . O repositório reúne código, documentos e histórico. O quadro já existe. Propomos quatro estados e cada tarefa com responsável, prazo e critério de conclusão. O exemplo no slide ilustra o fluxo, não representa o status real das tarefas. Confirmar a ferramenta com o professor. Exemplo de pronto: acionamento do botão gera o evento esperado e há registro do teste.

## 9. O cálculo acontece no dispositivo

Para explicar: o sensor mede aceleração em três direções perpendiculares, chamadas X, Y e Z. ax é a aceleração no eixo X; ay, no Y; az, no Z. Esses eixos acompanham a posição do sensor, não são direções fixas do ambiente. Elevamos cada leitura ao quadrado, somamos e tiramos a raiz. A é a magnitude: um único valor que resume a aceleração medida, incluindo a gravidade. Exemplo: ax=0, ay=0 e az=1 g resultam em A=1 g. É uma extensão do teorema de Pitágoras para três dimensões. O MPU6050 fornece aceleração nos três eixos em g. O ESP32 calcula a magnitude. Em repouso ela fica próxima de 1 g. Uma fase de queda livre pode se aproximar de zero; um impacto pode produzir um pico. A magnitude independe da orientação dos eixos, mas posição e fixação no corpo afetam a medição. O cálculo já está implementado; as regras de detecção ainda serão desenvolvidas. A decisão será local, enquanto o backend recebe e exibe o evento.

## 10. Redução de falsos positivos

Um pico isolado pode ocorrer ao sentar rapidamente, deitar ou bater o dispositivo. Estratégia a validar: considerar janela de tempo, impacto, orientação e movimento posterior. Limites e tempos serão ajustados com dados de teste. Não exigir queda livre ou imobilidade como condição universal: há quedas que não apresentam esses sinais. Comparar falsos alarmes e quedas não detectadas. Incluir queda do aparelho solto como limitação a investigar. Referências: https://www.mdpi.com/1424-8220/17/1/198 e https://pmc.ncbi.nlm.nih.gov/articles/PMC3353905/

## 11. Como vamos medir

Testar o algoritmo no computador com dados gravados, depois a integração no Wokwi. SisFall e FallAllD são candidatos sujeitos à conferência de licença e formato. Separar dados de ajuste e avaliação. Contar quedas detectadas, não detectadas e falsos alarmes. Detecção = detectadas / total de quedas testadas. Registrar duração ou atividades para contextualizar falsos alarmes. Ensaios curtos não comprovam menos de um alarme falso por dia. A configuração em menos de 15 minutos pode ser avaliada na demonstração, conforme aceite. Autonomia de 8 horas depende de hardware futuro. Todos os números são metas.

## 12. Hardware pensado para o dispositivo

Referência definida: Waveshare ESP32-S3-SIM7670G-4G. ESP32-S3 executa a lógica, GNSS fornece localização e modem envia alertas na proposta física. MPU6050 fornece aceleração e rotação. Visor touch de 1,69 polegada, botão manual, LED e buzzer, bateria 18650 e case completam a proposta. A integração do visor e seu custo ainda precisam ser validados. Sem compra neste semestre. A imagem é conceitual e medidas não foram validadas na placa física.

## 13. O desafio da placa e do case

O desafio foi chegar a uma placa e a um case que funcionem juntos e sejam adequados à proposta de uso. O modelo existe, mas as medidas e os encaixes ainda dependem da placa física. Precisaremos testar conforto, peso, estabilidade, leitura e uso da tela, acesso ao botão e pressão ao deitar, especialmente durante o sono. Essa avaliação física é futura, já que neste semestre não haverá montagem. A instituição poderá opinar sobre a proposta visual, mas isso não comprova conforto.

## 14. Por que o Wokwi

O Wokwi simula ESP32-S3, MPU6050, botão, LED e buzzer e executa firmware compilado com ESP-IDF. Permite repetir cenários sem aguardar hardware. Não simula a placa Waveshare completa. Planejamos localização por dados simulados e transporte pelo Wi-Fi virtual; GNSS e modem celular reais ficam sem validação. Confirmar Wokwi com professor: roteiro cita software livre. Fontes: https://docs.wokwi.com/guides/esp32 ; https://docs.wokwi.com/parts/wokwi-mpu6050 ; https://docs.wokwi.com/guides/esp32-wifi

## 15. Orçamento e alternativa comercial

MeuAmparo: estimativa documentada em setembro de 2026 para futura montagem, sem compra neste semestre. Placa R$459,99, frete R$8,90, MPU6050 R$28,10, bateria R$45 a R$70, botão/buzzer/LED R$15, pinos e fios R$10, PETG R$15, cinta/clip R$15. Total exato R$596,99 a R$621,99, arredondado no planejamento. Não inclui visor touch, trabalho de desenvolvimento, plano de dados ou hospedagem. A proposta com visor touch de 1,69 polegada foi confirmada pelo grupo; o custo da tela será cotado e o total revisado. Apple Watch SE 3: a partir de R$3.299 na loja oficial consultada em 16/09/2026; preço inicial não representa necessariamente a versão celular. Possui detecção de queda e SOS; comunicação depende de conectividade e configuração compatíveis. É um produto comercial, enquanto MeuAmparo é um projeto ainda em simulação, com personalização e código aberto como proposta. Não presumir desempenho, conforto ou confiabilidade equivalentes. Fontes: docs/projeto/01-entregas/md/Roteiro_2-Planejamento.md; https://www.apple.com/br/shop/buy-watch/apple-watch-se ; https://support.apple.com/pt-br/108896

## 16. Projeto aberto: GNU GPL v3

Escolhemos GNU GPL versão 3. Ela permite usar, estudar, modificar e compartilhar o código. Na distribuição de versões derivadas abrangidas pela GPL, a mesma licença e o acesso ao código-fonte correspondente preservam essas liberdades. Isso facilita continuidade e colaboração no projeto. Materiais e dependências de terceiros mantêm suas licenças. Fonte: LICENSE do repositório e https://www.gnu.org/licenses/gpl-3.0.html . Encerrar com os próximos passos: contato com instituição, confirmação do Wokwi e Kanban, e desenvolvimento dos cenários do detector.

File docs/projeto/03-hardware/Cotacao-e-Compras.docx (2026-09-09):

# MeuAmparo — Cotação de componentes

Levantamento de 09/set/2026, com preços consultados diretamente nas lojas. Decisão do grupo: comprar tudo no mercado nacional, sem importação.

## 1. A placa principal — o item que define o orçamento

Consultei a Amazon Brasil. O resultado muda a conta do projeto:

Produto | Preço | Entrega | Link | Observação
Waveshare ESP32-S3 + SIM7670G 4G — LTE Cat-1, Wi-Fi, Bluetooth, GNSS, multibanda global, antena integrada | R$ 459,99 (oferta alternativa) a R$ 710,81 | 22/set, frete R$ 8,90 | amazon.com.br/dp/B0CVVX749F | Melhor opção nacional
Placa ESP32-S3 SIM7670G 4G com carregamento solar/USB (mesma arquitetura, outro vendedor) | R$ 522,97 | 22/set, frete R$ 8,90 | amazon.com.br/dp/B0D54BCQJF | Alternativa direta
Waveshare SIM7600G-H, módulo de comunicação com GNSS | R$ 529,99 a R$ 845,70 | 19/set | busca na Amazon BR | Só o modem: ainda exigiria um ESP32 à parte
Waveshare SIM7600G-H-PCIE | R$ 1.404,53 | 22/set | busca na Amazon BR | Fora de escala para o projeto
Módulo SIM7600G com antenas — Curto Circuito | R$ 719,00 | — | curtocircuito.com.br/modulo-sim7600g-4g-lte-gps-antena-4g-gps.html | Esgotado
LilyGO T-SIM7000G — Smart Kits | R$ 589,90 | pronta entrega | smartkits.com.br/modulo-esp32-lilygo-ttgo-t-sim7000g-com-gps-e-gprs | NB-IoT/LTE-M, cobertura menos previsível que Cat-1

Busca completa na Amazon Brasil: amazon.com.br/s?k=esp32+4g+gps+sim7600 Documentação oficial da placa: waveshare.com/esp32-s3-sim7670g-4g.htm e docs.waveshare.com/ESP32-S3-SIM7670G-4G

Os dois códigos ASIN acima foram identificados pela descrição exata do anúncio visto na busca. Confira o título e a variante na página antes de comprar, porque a Amazon reaproveita o mesmo anúncio para versões diferentes da placa.

Recomendação: Waveshare ESP32-S3 SIM7670G, a R$ 459,99. Ela integra numa peça só o microcontrolador, o modem 4G, o GNSS, o Wi-Fi, o Bluetooth e a antena. Comprar módulo avulso sai mais caro e dá mais trabalho de montagem, que é justamente o que a proposta de kit replicável precisa evitar.

O ESP32-S3 ainda é um ganho técnico sobre o ESP32 comum: mais memória, mais desempenho e instruções vetoriais úteis se depois quisermos rodar um modelo de detecção embarcado.

### Sobre o Mercado Livre

Tentei consultar, mas o site exige login para exibir os resultados de busca, e eu não entro em conta sua. Se quiser os preços de lá, me mande o print ou o link do anúncio que eu comparo. Pela faixa observada em pesquisas anteriores, os anúncios de ESP32 com 4G e GPS no ML ficam entre R$ 250 e R$ 400, quase sempre de vendedores que também importam — prazo parecido com o da Amazon, sem a mesma previsibilidade de variante.

## 2. Lista de compras completa — tudo nacional

Item | Especificação | Preço | Onde comprar
Placa principal | Waveshare ESP32-S3 + SIM7670G 4G, com GNSS e antena integrada | R$ 459,99 | amazon.com.br/dp/B0CVVX749F
Frete da placa | — | R$ 8,90 | —
Sensor inercial | MPU6050, acelerômetro e giroscópio de 3 eixos | R$ 28,10 | curtocircuito.com.br/modulo-acelerometro-3-eixos-mpu6050.html (conferir estoque)Alternativa: amazon.com.br/dp/B07GHX76M6
Bateria | Li-ion 18650, 3500 mAh, Samsung ou LG genuína | R$ 45 a R$ 70 | amazon.com.br/s?k=bateria+18650+3500mah+samsung
Interface | Botão táctil 12 mm, buzzer 5 V, LED | R$ 15 | eletrogate.com · curtocircuito.com.br
Conexões | Barras de pinos, jumpers, parafusos M2 | R$ 10 | eletrogate.com · curtocircuito.com.br
Case | Filamento PETG, fração do rolo | R$ 15 | amazon.com.br/s?k=filamento+petg+1kg
Fixação | Cordão com engate de segurança e clipe de cinto | R$ 15 | papelaria ou marketplace
| Total estimado | R$ 597 a R$ 622

### A conta mudou, e você precisa saber disso

O teto de R$ 500 por unidade que tínhamos assumido não fecha comprando tudo no Brasil. Só a placa consome R$ 460 dos R$ 500.

Cenário | Custo por unidade | Prazo | Nota fiscal e garantia
Tudo nacional (decisão atual) | R$ 597 a R$ 622 | 13 dias | sim
Placa importada + resto nacional | R$ 360 a R$ 400 | 20 a 45 dias | não, na placa

A diferença é de cerca de R$ 220 por unidade. Em troca, você recebe em 13 dias, com nota, garantia e sem risco de vir a variante errada do módulo. Para um protótipo único com prazo de entrega em 25/nov, essa troca me parece boa. Para uma ONG replicar dez unidades, não — e vale registrar isso na documentação do projeto, porque é uma informação útil para quem for replicar depois.

Sugestão para o roteiro: informar R$ 620 por unidade como custo real do protótipo, e citar a rota de importação como alternativa de menor custo para replicação em escala, com o prazo maior como contrapartida.

## 3. Lojas nacionais que valem consulta

Curto Circuito · Eletrogate · Smart Kits · Usinainfo · Baú da Eletrônica · Robocore · Autocore Robótica · Amazon Brasil · Mercado Livre

Nas consultas de hoje, dois dos itens procurados em loja especializada estavam esgotados. Para um kit pensado para replicação, isso precisa constar da documentação, com fornecedor alternativo indicado para cada item.

## 4. Cuidados na compra

Confirme a banda do modem. O SIM7670G é multibanda global e cobre as faixas brasileiras. Se optar por outro modelo, evite variantes europeias, que têm cobertura ruim na B28 de 700 MHz — a que pega no interior.

Bateria 18650 falsificada. Anúncio de 9900 mAh por R$ 15 é mentira: a maior 18650 real tem cerca de 3600 mAh. Compre Samsung, LG ou Sony de vendedor com reputação, ou a autonomia do projeto vira ficção.

Compre duas placas se o orçamento permitir. Uma queima na bancada e você fica sem protótipo na semana da entrega. Se não der, saiba que o Roteiro de Extensão aceita desenvolvimento e teste por simulação computacional em software livre, citando o SimulIDE. A entrega não depende do hardware chegar.

## Fontes consultadas em 09/set/2026

- Amazon Brasil — busca por "esp32 4g gps sim7600", 16 resultados, preços e prazos conforme tabela
- Curto Circuito — módulo SIM7600G 4G LTE GPS com antenas: R$ 719,00, esgotado
- Curto Circuito — MPU6050: R$ 28,10
- Smart Kits — LilyGO T-SIM7000G: R$ 589,90, pronta entrega
- Mercado Livre — consulta bloqueada por exigência de login

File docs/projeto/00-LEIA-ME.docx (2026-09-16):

# MeuAmparo — índice dos documentos

Dispositivo aberto de detecção de queda e localização para pessoas idosas Projeto de extensão · Programação de Microcontroladores (ARA4710) · Estácio Ribeirão Preto · 2026.2 Docente orientador: Prof. Omar Sacilotto Donaires

## Como esta pasta está organizada

### 01-entregas — o que vai para a SAVA

Arquivo | O que é | Prazo
MeuAmparo_Roteiro_1-Diagnostico-e-Teorizacao.pdf | Entrega 1, seções 1.1 a 1.5. É este arquivo que se posta na SAVA | 09/set · 2,0 pontos
MeuAmparo_Roteiro_1-Diagnostico-e-Teorizacao.docx | A mesma entrega em Word, para editar | —
MeuAmparo_Roteiro_2-Planejamento.docx | Entrega 2, seções 2.1 a 2.5, com o cronograma em Gantt e o roteiro de fala do seminário | 23/set · 1,0 ponto
MeuAmparo_Canvas-Projeto_preenchido.docx | Canvas do projeto, com os 11 blocos preenchidos | apresentado nos seminários

A entrega na SAVA é em PDF, uma por grupo. O .docx serve para editar antes de gerar o PDF final.

### 02-parte-interessada — a instituição

Arquivo | O que é
MeuAmparo_Instituicoes-Ribeirao-Preto.docx | 19 instituições candidatas, com telefone, separadas por perfil, mais o roteiro da ligação e as 8 perguntas da visita
email_professor_omar.txt | Mensagem ao professor apresentando a proposta e pedindo o aceite para convidar mais colegas

### 03-hardware — o dispositivo

Arquivo | O que é
MeuAmparo_Cotacao-e-Compras.docx | Cotação nacional com links, preços e prazos. Custo do protótipo: R$ 597 a R$ 622
MeuAmparo_Case_e_Posicionamento.docx | Projeto do case, o que medir na placa, especificação de impressão e o protocolo de teste de posicionamento
case/meuamparo_case.scad | Modelo paramétrico do case em OpenSCAD
case/meuamparo_case_base.stl | Base, pronta para enviar ao serviço de impressão
case/meuamparo_case_tampa.stl | Tampa, pronta para enviar
case/case_conjunto.png | Vista das duas peças

### 04-figuras — imagens para os documentos e slides

gantt_cronograma.png — cronograma do projeto de setembro a novembro.

### 05-fontes-markdown — os originais

Arquivos .md que geram os .docx e o .pdf. Editar aqui e reconverter mantém a formatação consistente entre as versões.

## Onde o projeto está

Definido. Nome MeuAmparo. Licença GNU GPL v3. Placa Waveshare ESP32-S3 SIM7670G com 4G, GNSS, Wi-Fi e Bluetooth. Firmware em ESP-IDF, linguagem C. Sensor MPU6050. Bateria 18650. Case de 117,4 × 37,8 × 30,0 mm, com clipe de cinto e cordão. Dois problemas atendidos: a queda e o afastamento de quem tem quadro demencial.

Em aberto. A instituição parceira, ainda em prospecção. Os nomes e matrículas do grupo. As medidas exatas da placa, que só saem com ela em mãos.

## Calendário

Data | O que acontece | Pontos
09/set | Entrega: Diagnóstico e Teorização | 2,0
16/set | Seminário de planejamento | —
21/set | Prazo de submissão do III EPEI | —
23/set | Entrega: Planejamento do projeto | 1,0
28/out | Seminário de desenvolvimento | —
25/nov | Entrega final e seminário de avaliação | 7,0

Aprovação exige grau igual ou superior a 6,0 e frequência de ao menos 75%.

## Três coisas que travam o resto

A instituição. Sem ela, a seção 2.2 fica sem conteúdo em 23/set, e não há como registrar as evidências que o roteiro exige. Comece pelo Conselho Municipal do Idoso, no telefone (16) 3611-6017.

O grupo. Sem os nomes, não sai a carta de apresentação nem a seção 2.3.

A placa. O prazo de entrega é 22/set. Encomendar cedo dá margem para o case, os testes e um eventual imprevisto.

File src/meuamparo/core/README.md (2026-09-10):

# core

C puro. Nenhum header do ESP-IDF, nenhuma chamada ao FreeRTOS, nenhum acesso direto a hardware.

Contém a detecção de queda, o geofence, a máquina de estados do dispositivo e a declaração da
interface de transporte. Recebe dados prontos e devolve decisões.

A razão de existir: o algoritmo precisa rodar em segundos no Mac contra centenas de traces para
que a meta de 90% de detecção seja medida, e não estimada. Se depender do ESP-IDF, cada ajuste de
limiar vira um ciclo de gravar e testar na placa.

Quem implementa as bordas é `../firmware/` na placa e `../test/` no host.

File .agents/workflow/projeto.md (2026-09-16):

# O projeto

MeuAmparo é uma proposta de dispositivo vestível de baixo custo para pessoas idosas: detectar
quedas, permitir pedido manual de ajuda e avisar cuidadores sobre a localização e a saída de uma
área segura, principalmente em casos de desorientação. O projeto de extensão prevê parceria com uma
instituição de Ribeirão Preto, documentação aberta sob licença GNU GPL v3 e uma oficina para que a equipe
consiga montar, configurar e operar o dispositivo.

Disciplina Programação de Microcontroladores (ARA4710), Estácio Ribeirão Preto, semestre 2026.2,
orientação do Prof. Omar Sacilotto Donaires.

Discentes:

- Luis Gustavo Moda
- Isabelly Vitoria

O grupo está definido. Menção a "discentes a definir" ou "grupo em formação" em qualquer arquivo
está desatualizada.

## Arquitetura prevista

ESP32, sensor inercial MPU6050, GNSS, conectividade 4G, bateria 18650, botão de pânico, buzzer e
LED. Firmware em C com ESP-IDF. Backend e painel web de alertas e histórico também estão previstos,
sem stack definida. A proposta fala em cuidado com dados pessoais e hospedagem no Brasil; isso não
comprova conformidade com a LGPD e não deve ser apresentado como se comprovasse.

## Metas documentadas

Detectar pelo menos 90% das quedas simuladas, menos de um alarme falso por dia, alerta de saída da
área segura em até dois minutos, autonomia mínima de oito horas, configuração independente em menos
de 15 minutos e avaliação de pelo menos 4/5.

São metas, não resultados. O protocolo do case usa outra métrica de alarme falso, medida por
atividade; são critérios diferentes e não devem ser somados nem confundidos.

## Divergências abertas

Em 16/09/2026 o grupo escolheu a Waveshare ESP32-S3-SIM7670G-4G como plataforma de referência,
com estimativa de R$ 597 a R$ 622 por unidade, e decidiu não comprar: não há tempo hábil até a
entrega. Não existe hardware físico neste semestre; não fale em compra, montagem ou teste físico
como algo previsto. Os dois canvas, o Roteiro 2 em Word e o Markdown de compras ainda
citam a LilyGO T-A7670G R2 importada (R$ 419, teto de R$ 500); isso é texto desatualizado, não
alternativa em aberto. Os valores são estimativas de setembro de 2026, não preço atual nem
comprovante de compra.

O desenvolvimento e os testes são só em simulação, no Wokwi, que é o caminho previsto no roteiro
da disciplina. O roteiro cita software livre e o Wokwi não é; a
escolha ainda precisa ser confirmada com o professor. O Wokwi não tem peça de GNSS nem de modem
celular.

O calendário oficial foi atualizado na Aula 04: seminário de diagnóstico (workshop de canvas) em
02/09, entrega do diagnóstico em 09/09, seminário de planejamento em 16/09, entrega do planejamento
em 23/09, seminário de desenvolvimento em 28/10 e entrega final com seminário de avaliação em
25/11/2026. A Aula 01 e o Canvas trazem as datas antigas (26/08, 02/09 e 21/10).

## Hardware e case

Existem documentos de diagnóstico, planejamento, canvas, prospecção de instituições, cotação,
identidade visual e o modelo paramétrico do case em OpenSCAD, com STL da base e da tampa. O case foi
desenhado para a Waveshare: medidas e encaixes precisam ser conferidos com a placa física antes de
mandar fabricar.

Cintura, peito e braço são posições propostas para avaliação, não decididas. O cordão precisa de
engate de segurança. Teste de queda usa adulto saudável em ambiente controlado, nunca pessoa idosa.

## Parte interessada

Em 09/09/2026 a instituição parceira ainda estava pendente. Casa do Vovô, Lar Padre Euclides e Lar
do Vovô Albano aparecem como candidatas. Prospecção não é parceria firmada, rascunho de e-mail não é
mensagem enviada, atividade planejada não é atividade realizada. A escuta da instituição orienta os
requisitos e a avaliação, com registro das evidências e das autorizações.

## Entrega

Os documentos preveem envio em PDF pela SAVA e citam simulação como alternativa à montagem física.
Confirme a exigência da disciplina e a compatibilidade do simulador antes de depender dessa
alternativa.

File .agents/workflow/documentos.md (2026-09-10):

# Documentos acadêmicos

Vale para tudo que vai para a disciplina: roteiro, canvas, relatório, apresentação.

Antes de redigir, abra o modelo oficial em `docs/material-disciplina/`, as orientações da aula
correspondente e os arquivos já escritos. Preserve a estrutura exigida e confira o calendário. Não
presuma regra de formatação nem declare conformidade sem ter verificado.

## Redação

Português natural e direto, no nível do trabalho. Aplique a skill `humanizer-pt-br` antes de
entregar. Sem texto genérico, sem repetição, sem série de ressalvas, sem subtítulo que não organiza
nada. Primeira pessoa só para decisão ou experiência que o grupo confirmou.

## Verificação

Confira autoria, título, data e se a fonte citada sustenta mesmo a afirmação. Nunca invente
referência, entrevista, participante, aprovação, compra, medição ou resultado. Diferencie proposta,
meta, atividade realizada e resultado medido — o texto perde valor quando mistura os quatro.

Resolva as inconsistências entre objetivo, método, cronograma e orçamento. Quando a decisão for
minha, apresente as alternativas e deixe o ponto explicitamente pendente. Não transforme hipótese em
decisão só para o texto ficar mais convincente.

## O que não pode sobrar no arquivo entregue

Marcador do tipo "[PREENCHER]", "[PENDÊNCIA]" ou "atualizar esta resposta". Comando de edição.
Comentário interno. Liste as lacunas de forma objetiva fora do documento acadêmico e não esconda a
falta de evidência exigida.

## Antes de dizer que está pronto

Confira a coerência entre Word, Markdown, canvas e o que mais foi alterado. Renderize o documento
final e olhe todas as páginas: corte de tabela, legenda solta e quebra de página no lugar errado só
aparecem no PDF.

Se faltar decisão ou evidência obrigatória, entregue como versão para revisão e diga exatamente o
que falta.

## Uso de IA

O objetivo é um trabalho correto, verificável e que o grupo consiga explicar na banca. Não introduza
erro de propósito, não falsifique metadado, não simule histórico de edição para disfarçar assistência
de IA. Respeite as regras da disciplina sobre uso e declaração, e nunca prometa aprovação nem
ausência de detecção.

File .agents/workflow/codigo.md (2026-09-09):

# Código

Trabalho de código acontece em `src/meuamparo/`. A regra que organiza tudo é a fronteira entre as
pastas, explicada com o porquê em `src/meuamparo/README.md`:

- `core/` é C puro. Nenhum header do ESP-IDF, nenhum FreeRTOS, nenhum acesso a hardware.
- `firmware/` só recebe o que roda no ESP32-S3. Nenhum trace, mock ou cenário.
- `simulator/` pode depender de qualquer coisa, porque não vai para a placa.
- `test/` roda no host, sem toolchain de embarcado.

Essa separação existe para medir a meta de 90% de detecção rodando o algoritmo contra centenas de
traces em segundos, no Mac. Proposta que quebre a fronteira precisa justificar por que vale perder
isso.

## Comandos

```
make help    lista os alvos
make test    compila e roda os testes de host
make clean   apaga build/
```

O Makefile usa `-Werror`. Aviso de compilador quebra o build de propósito.

Alvo novo precisa de um comentário `## descrição` na própria linha, senão não aparece no `make help`.

## Como fechar uma tarefa

O plano de oito passos em `src/meuamparo/README.md` dá um critério de verificação por passo. Siga a
mesma regra em qualquer tarefa nova: passo sem critério verificável não conta como pronto. "Compila"
não é critério; "make test passa" é.

## Convenções em uso

Identificador em inglês com prefixo `ma_`: `ma_imu_sample_t`, `ma_accel_magnitude`. Comentário em
português, explicando a decisão e o motivo, não o que a linha já diz. Header com include guard
`MEUAMPARO_<ARQUIVO>_H`.

Os README e o `core/include/meuamparo/imu.h` são a referência de tom. Aquele comentário explica
por que usar magnitude em vez dos eixos separados — é esse nível que se espera, e não "calcula a
magnitude".

O repositório ainda não tem nenhum commit, então o idioma da mensagem de commit está em aberto.
Pergunte antes de assumir.

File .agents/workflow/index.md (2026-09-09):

# MeuAmparo — instruções do repositório

Dispositivo vestível de baixo custo para pessoas idosas: detecta queda, aceita pedido manual de
ajuda e avisa o cuidador com a localização. Trabalho de extensão da disciplina Programação de
Microcontroladores (ARA4710), Estácio Ribeirão Preto, 2026.2.

`AGENTS.md` e `CLAUDE.md` na raiz são ponteiros para este arquivo. O conteúdo mora aqui.

## Onde está cada coisa

@projeto.md
@estrutura.md
@codigo.md
@documentos.md

- `projeto.md` — contexto, grupo, arquitetura, metas, divergências abertas, parte interessada
- `estrutura.md` — o que tem em cada pasta de `docs/` e de `src/`
- `codigo.md` — fronteira entre core, firmware e simulador; comandos do Makefile; convenções
- `documentos.md` — regras para as entregas da disciplina

## Sempre

Responda em português, direto.

Separe as quatro coisas que este projeto vive confundindo: decisão registrada, proposta, pendência e
resultado verificado. Meta documentada não é resultado obtido. Prospecção não é parceria. Estimativa
de setembro de 2026 não é preço atual.

Quando os arquivos se contradisserem, aponte a contradição em vez de escolher um lado sozinho. Boa
parte da documentação tem duas versões que ainda não foram conciliadas.

Não invente participante, entrevista, aprovação, compra, medição nem teste.

Eu decido, você executa. Havendo opção relevante, apresente em poucas linhas e espere minha escolha.

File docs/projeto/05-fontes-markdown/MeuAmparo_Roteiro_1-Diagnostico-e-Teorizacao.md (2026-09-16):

# MeuAmparo

**Dispositivo aberto de detecção de queda e localização para pessoas idosas**

Sociedade de Ensino Superior Estácio de Ribeirão Preto
Bacharelado em Ciência da Computação
Disciplina: Programação de Microcontroladores (ARA4710) — 2026.2
Docente orientador: Prof. Omar Sacilotto Donaires
Discentes: a definir
Ribeirão Preto / SP — setembro de 2026

---

# 1. Diagnóstico e teorização

## 1.1 Identificação das partes interessadas e parceiros

### Situação atual da parceria

A instituição parceira está **a definir**. O grupo iniciou a prospecção em setembro de 2026, partindo da relação oficial de organizações cadastradas no Conselho Municipal do Idoso de Ribeirão Preto, cujos registros são válidos até 31 de março de 2028. A escolha por essa fonte não é acidental: entidades ali inscritas já passaram pelo crivo do conselho municipal, o que dispensa verificação adicional de idoneidade e assegura que atuam formalmente com a população idosa do município.

### Perfil do público participante pretendido

Independentemente de qual instituição venha a firmar a parceria, o público participante direto é composto por pessoas com 60 anos ou mais, de ambos os sexos, atendidas por entidade sem fins lucrativos de Ribeirão Preto. O perfil socioeconômico predominante nessas organizações é de baixa renda, com sustento vindo de aposentadoria ou benefício assistencial, e escolaridade concentrada no ensino fundamental incompleto. Estima-se de 15 a 40 participantes, número a ser confirmado com a instituição.

Dentro desse público, dois subgrupos concentram o risco que o projeto pretende endereçar. O primeiro reúne pessoas com mobilidade reduzida, que fazem uso de bengala ou andador e apresentam histórico de queda. O segundo é formado por pessoas com quadro demencial, sujeitas à desorientação espacial e ao afastamento não percebido do local onde vivem.

O público indireto é composto pelos cuidadores formais, responsáveis pelo acompanhamento diário e pelo primeiro socorro; pelos familiares de referência, que hoje só tomam conhecimento de uma ocorrência quando a instituição consegue telefonar; e pela coordenação técnica, a quem cabe decidir sobre a adoção de qualquer tecnologia no ambiente.

### Instituições em prospecção

O grupo organizou as candidatas em quatro perfis, conforme a natureza do atendimento e a aderência ao problema:

**Instituições de longa permanência de caráter filantrópico.** É o perfil de maior aderência, porque os residentes vivem no local, existe equipe de cuidadores e a queda noturna sem testemunha é o cenário concreto.

| Instituição | Registro CMI | Aderência observada |
|---|---|---|
| Sociedade Espírita Cinco de Setembro (Casa do Vovô) | 004 | Mantém os projetos "Conexão Digital 60+" e "Rede de Proteção 60+", o que indica abertura declarada a soluções tecnológicas |
| Lar Padre Euclides | 006 | Desenvolve o projeto "Viver em Movimento — Reabilitação Funcional e Qualidade de Vida da Pessoa Idosa", diretamente ligado ao risco de queda |
| Associação Assistencial Maria de Nazaré (Lar do Vovô Albano) | 005 | Cinco projetos ativos voltados ao público 60+, incluindo "Bem Viver 60+: Cuidado Integral e Proteção à Pessoa Idosa" |
| Lar dos Velhos da Igreja Presbiteriana (Lar Presbiteriano Lili Ribeiro) | 002 | Abrigo institucional com o projeto "Viver Ativo" |
| Associação de Caridade Santa Rita de Cássia | 003 | Modalidade casa-lar, com grupo reduzido, o que facilita a implantação e o acompanhamento |
| Comunidade Missionária Divina Misericórdia (Casa Santa Dulce dos Pobres) | 034 | Acolhimento institucional |

**Centros-dia.** A pessoa idosa vai e volta diariamente, o que torna relevante o alerta de afastamento da área segura: Cantinho do Céu (registro 031), Instituto Limite, com o Centro Dia do Idoso Viver (028), e o Centro Dia do Idoso da APAE de Ribeirão Preto (015).

**Serviços de atendimento domiciliar.** Aqui a pessoa mora sozinha, e é onde a localização por satélite mais faz diferença, já que não há ninguém por perto quando a queda acontece: Instituto de Desenvolvimento Social Caminhando com Amor, que opera o Serviço de Atendimento Domiciliar (017), ABRACCIA (013), Associação S.O.S. Vidas (020) e Centro de Referência Popular (035).

**Parceria de caráter acadêmico.** A Fundação de Apoio ao Ensino, Pesquisa e Assistência, FAEPA (021), mantém o projeto "60+ Ninguém fica para trás". Traria peso institucional ao trabalho, em contrapartida a um processo de aprovação previsivelmente mais longo.

### Critérios de escolha

A definição da parceira observará quatro critérios, nesta ordem: existência de demanda real declarada pela própria instituição durante a visita de escuta; disponibilidade da equipe para participar do desenvolvimento e dos testes; autorização para registro fotográfico e em vídeo, exigência do roteiro de extensão; e proximidade geográfica, que viabiliza os encontros presenciais dentro do semestre.

### Formalização prevista

Definida a instituição, a parceria será formalizada pela Carta de Apresentação emitida pela Estácio, pela Carta de Autorização assinada pela entidade e por termo de acordo de cooperação. Esses documentos, somados ao termo de autorização de uso de imagem, serão anexados a este roteiro como evidência, conforme exigido.

---

## 1.2 Problemática e problemas identificados

### O país envelhece, e depressa

Segundo as Projeções da População do IBGE (2024), a parcela de brasileiros com 60 anos ou mais saltou de 8,7% em 2000 para 15,6% em 2023, o equivalente a 33 milhões de pessoas, e deve alcançar 37,8% da população em 2070. A idade média do país subiu de 28,3 para 35,5 anos no mesmo intervalo. Não se trata de uma demanda passageira, mas de uma pressão crescente e previsível sobre a rede de cuidado.

### A queda deixou de ser acidente isolado

Silva et al. (2023), analisando os dados do Sistema de Informações Hospitalares do SUS entre 2000 e 2020, encontraram crescimento sustentado tanto das internações quanto dos gastos por quedas na população idosa. No estado de São Paulo, a variação percentual anual média foi de 4,3% nas internações e 8,5% nos custos totais. Os autores projetam que, em 2025, as internações por quedas no Brasil ficariam **próximas de 150 mil, gerando cerca de R$ 260 milhões em custos para o SUS**.

A dimensão do problema aparece também em outros indicadores citados no mesmo estudo. O Estudo Longitudinal da Saúde dos Idosos Brasileiros (ELSI-Brasil) verificou que **25,1% de 4.533 idosos sofreram queda entre 2015 e 2016**, com 1,8% dos casos resultando em fratura de quadril ou fêmur, das quais 31,8% exigiram cirurgia com colocação de prótese. Extrapolando para a população urbana brasileira, os autores estimam **cerca de 6,2 milhões de idosos brasileiros caídos no período de um ano**. Entre 2002 e 2016, o SUS gastou **mais de R$ 1 bilhão** apenas com internações de pessoas idosas por fratura de fêmur.

O risco cresce com a idade. Entre as pessoas que caem, a distribuição por faixa etária é de 26,1% entre 60 e 69 anos, 32,4% entre 70 e 79 anos e 38,1% acima dos 80 — justamente o perfil predominante em instituições de longa permanência.

### O que agrava o desfecho é o tempo até o socorro

Não é apenas a queda que determina a gravidade, mas o intervalo entre ela e o atendimento. Uma pessoa idosa que cai sozinha e não consegue se levantar nem pedir ajuda pode permanecer horas no chão, o que eleva o risco de desidratação, hipotermia, complicações renais e agravamento de fraturas. A queda noturna, a caminho do banheiro, é das mais frequentes e costuma acontecer sem testemunhas.

### A desorientação súbita é o segundo problema

A queda não é o único evento repentino que expõe a pessoa idosa. Entre residentes com quadro demencial, a desorientação espacial faz com que a pessoa saia sozinha, perca a referência do caminho de volta e não consiga pedir ajuda nem informar onde mora. O intervalo entre a saída e a percepção de que ela não está mais no local determina a chance de encontrá-la, e esse intervalo depende hoje de alguém notar a ausência. Os desfechos vão da exposição prolongada ao sol ou ao frio até o atropelamento e o desaparecimento.

São problemas de naturezas distintas, mas de estrutura idêntica: um evento súbito, sem testemunha, em que o tempo de resposta define a gravidade. E ambos se resolvem com a mesma solução técnica, que é saber onde a pessoa está e ser avisado imediatamente.

### O mercado não atende quem mais precisa

O levantamento de preços realizado pelo grupo em setembro de 2026 identificou quatro categorias de solução disponíveis no Brasil:

| Categoria | Faixa de preço | Limitação observada |
|---|---|---|
| Relógios e pulseiras 4G importados, com GPS e detecção de queda | cerca de R$ 220 a R$ 230 | Aplicativo e servidor estrangeiros, sem base legal definida para o tratamento de dados no Brasil; configuração feita por comandos SMS que o familiar não domina; ausência de suporte; detecção no pulso com alta taxa de alarme falso |
| Kits de botão de emergência sem fio, com base receptora | cerca de R$ 380 a R$ 450 | Alcance limitado ao interior da residência, sem localização e sem detecção automática |
| Serviços de teleassistência com central 24 horas | mensalidade recorrente | Custo continuado incompatível com o orçamento de instituição filantrópica |
| Relógios inteligentes de linha | acima de R$ 2.500 | Preço inviável para o público atendido |

Entre o dispositivo importado barato, sem suporte e sem garantia de privacidade, e o serviço de teleassistência com mensalidade, não existe alternativa acessível. É nesse vão que o projeto se posiciona.

### Estágio do diagnóstico

O diagnóstico apresentado até aqui é documental, construído a partir de dados oficiais, literatura científica e levantamento de mercado. O diagnóstico de campo, com a escuta da instituição parceira, está previsto no cronograma para a segunda quinzena de setembro e será incorporado a este roteiro assim que realizado. Dele devem sair a caracterização precisa do público atendido, o histórico de quedas e de episódios de desorientação no local, os recursos hoje utilizados e as prioridades apontadas pela própria equipe.

### Problema priorizado

Pessoas idosas atendidas por instituições filantrópicas de Ribeirão Preto não dispõem de um meio confiável e financeiramente acessível de acionar socorro quando sofrem uma queda estando sozinhas, ou quando se afastam desorientadas do local onde vivem. As instituições que as atendem não têm como adquirir nem manter as soluções existentes no mercado.

---

## 1.3 Justificativa

### O que muda para a pessoa idosa

Cair sozinha e permanecer horas no chão sem conseguir pedir ajuda deixa de ser um desfecho possível. O dispositivo identifica a queda pela assinatura do próprio movimento e dispara o alerta em segundos, informando a localização, ainda que a pessoa esteja desacordada ou sem forças para acionar qualquer coisa. Para quem tem quadro demencial, o afastamento da área segura gera aviso imediato, enquanto ainda há tempo de alcançá-la.

### O que muda para o cuidador e para a família

Hoje a queda é descoberta por acaso: na ronda seguinte, quando alguém ouve o barulho, ou quando a instituição consegue telefonar para o familiar. Com o dispositivo, o aviso chega na hora e informa onde a pessoa está, o que transforma um resgate incerto em resposta dirigida. Para a instituição, isso significa cobrir mais residentes com a mesma equipe, sem ampliar a ronda noturna.

### Por que não simplesmente comprar pronto

As soluções de mercado cobram mensalidade, dependem de aplicativo e servidor hospedados fora do país e são configuradas por comandos SMS que ninguém na instituição domina. O desfecho prático é conhecido: o aparelho é comprado, ninguém consegue configurar, e termina na gaveta. Soma-se a isso a dependência de um fornecedor que pode encerrar o serviço a qualquer momento, sem qualquer garantia sobre o destino dos dados de localização dos residentes.

### Por que o projeto é aberto

Publicando o esquema elétrico, a lista de materiais com fornecedores, o modelo do case e o código-fonte sob licença GNU GPL v3, a instituição passa a conseguir montar as unidades seguintes por conta própria, pagando apenas o preço das peças, sem depender do grupo depois que o semestre acabar. Para uma organização filantrópica, essa autonomia vale mais do que receber um protótipo pronto.

### A lacuna foi verificada projeto a projeto

Em setembro de 2026 o grupo levantou os projetos abertos de detecção de queda publicados no GitHub e comparou cada um com os requisitos desta proposta:

| Projeto | O que faz | O que não cobre |
|---|---|---|
| Kartik9250/Fall_detection | ESP32 com MPU6050, buzzer, botão para cancelar o alarme, gerenciador de rede Wi-Fi e envio de SMS de emergência | Não tem GPS nem conectividade celular própria, e não há servidor nem painel de acompanhamento |
| shivaywadhawan/Fall-Detection | ESP32-S3 com MPU6050 posicionado no peito, voltado ao estudo do algoritmo de detecção | Entrega apenas o algoritmo: sem localização, sem alerta a distância e sem documentação de montagem |
| geoseiden/fall-detection-blynk | ESP32 com MPU6050 e monitoramento pela plataforma Blynk | Depende de plataforma comercial de terceiros, com dados hospedados fora do país e cobrança por dispositivo |
| tonlongthuat/Real-Time-Fall-Detection | Detecção por visão computacional, com ESP32-CAM e a rede YOLO | Exige câmera instalada no ambiente da pessoa idosa, o que levanta objeção de privacidade em quarto e banheiro; não é dispositivo vestível |

Nenhum dos quatro reúne, ao mesmo tempo, conectividade celular autônoma com localização, tratamento de dados hospedado no Brasil, configuração acessível a quem não é técnico e documentação voltada à replicação por uma organização social. Há ainda trabalhos acadêmicos próximos, como o sistema de detecção com ESP32 e Edge Impulse publicado pelo IEEE e o dispositivo vestível descrito no *International Journal of Engineering Inventions*, ambos centrados no desempenho do algoritmo e sem tratar da replicação por terceiros. O projeto, portanto, não parte do zero nem repete o que já existe.

### Relação com a formação e motivação do grupo

Resolver esse problema exige selecionar um dispositivo microcontrolado a partir de requisitos reais e conflitantes entre si, como consumo de energia, tamanho físico, custo unitário e periféricos disponíveis; desenvolver firmware em linguagem C; e integrar sensores por I²C e UART. São as competências centrais da disciplina, exercitadas sobre uma demanda concreta e não sobre um exercício montado para caber no conteúdo.

A motivação do grupo vem de uma constatação simples: a tecnologia necessária para resolver esse problema já existe, é barata e está ao alcance de estudantes de graduação. O que falta não é capacidade técnica, é alguém disposto a montar a solução para quem não pode pagar por ela. É um trabalho em que a competência técnica que estamos desenvolvendo tem efeito direto e verificável sobre a vida de pessoas concretas, e essa possibilidade foi o que levou o grupo a escolher o tema.

---

## 1.4 Objetivos, resultados e efeitos a serem alcançados

1. **Desenvolver** um dispositivo vestível de baixo custo capaz de detectar automaticamente a queda de uma pessoa idosa, alertar sobre o afastamento da área segura e acionar seus cuidadores informando a localização, permitindo também o acionamento manual por botão.

2. **Documentar** o hardware e o firmware como projeto aberto, sob licença GNU GPL v3, incluindo lista de materiais com fornecedores, roteiro de montagem e instruções de configuração, de modo que a instituição consiga replicar unidades adicionais sem apoio técnico externo.

3. **Capacitar** a equipe da instituição a montar, configurar, testar e operar o dispositivo, verificando essa capacitação por meio de oficina prática ao final do projeto.

### Participação do público na avaliação

O atingimento dos objetivos será verificado com a participação direta dos envolvidos, por três instrumentos. O primeiro é o teste assistido de detecção, em que voluntários da equipe simulam quedas em ambiente controlado, com registro de acertos, falhas e alarmes falsos. O segundo é o exercício de autonomia, em que um membro da equipe configura um dispositivo do zero, sem intervenção do grupo, com o tempo cronometrado. O terceiro é a avaliação de reação, por formulário aplicado à coordenação e aos cuidadores, complementada por depoimento em vídeo.

---

## 1.5 Referencial teórico

O projeto se apoia em cinco eixos teóricos: o envelhecimento populacional, a epidemiologia das quedas, a detecção automática por acelerometria, o projeto de sistemas embarcados e, por fim, a metodologia de condução somada ao marco legal aplicável.

**Envelhecimento populacional.** As Projeções da População do IBGE (2024) estabelecem a base demográfica do problema. A população brasileira deve parar de crescer em 2041, com máximo de 220,4 milhões de habitantes, enquanto a proporção de pessoas com 60 anos ou mais praticamente dobrou entre 2000 e 2023 e caminha para 37,8% em 2070. O dado sustenta a afirmação de que a demanda por soluções de cuidado tende a crescer de forma previsível nas próximas décadas.

**Epidemiologia e custo das quedas.** Silva et al. (2023), em *Ciência & Saúde Coletiva*, analisaram a série histórica de internações, óbitos e custos por quedas na população idosa entre 2000 e 2020, a partir do Sistema de Informações Hospitalares do SUS, com regressão por *joinpoint* e cálculo da variação percentual anual média. Encontraram crescimento em todos os segmentos analisados e projetaram, para 2025, cerca de 150 mil internações e R$ 260 milhões em custos. O trabalho é central para este projeto por dois motivos: quantifica o problema em termos que uma banca e uma instituição reconhecem, e demonstra que a tendência é de agravamento, o que justifica investir em detecção precoce em vez de apenas em atendimento posterior. O mesmo estudo reúne indicadores complementares, entre eles os do ELSI-Brasil, que apontam prevalência de queda de 25,1% em coorte de 4.533 idosos, e o gasto superior a R$ 1 bilhão do SUS com internações por fratura de fêmur entre 2002 e 2016.

**Detecção automática de queda por acelerometria.** Sucerquia, López e Vargas-Bonilla (2017), em "SisFall: A Fall and Movement Dataset", publicaram o conjunto de dados que se tornou referência na área, com registros de acelerômetro e giroscópio de quedas simuladas e de atividades cotidianas. O trabalho é relevante aqui por duas razões. Descreve a assinatura característica de uma queda, composta por queda livre, impacto, mudança de orientação e imobilidade posterior, e é essa sequência que fundamenta o algoritmo a ser implementado no firmware. E evidencia o problema central da área, que é distinguir a queda de atividades cotidianas de perfil semelhante, como sentar-se bruscamente. O posicionamento do sensor próximo ao centro de massa, adotado no conjunto de dados, orienta diretamente a decisão de projeto sobre onde o dispositivo deve ser usado.

**Sistemas embarcados e programação de microcontroladores.** Almeida (2016), em *Programação de Sistemas Embarcados*, fornece o método de seleção de dispositivo a partir de requisitos e as práticas de desenvolvimento de firmware em linguagem C, que é o núcleo do problema proposto pela disciplina. Monk (2017) e Zanco (2010) oferecem o contraponto entre famílias e arquiteturas distintas, necessário para que a escolha do microcontrolador seja justificada por comparação, e não por conveniência ou hábito.

**Metodologia e marco legal.** A condução do projeto segue Bender (2015), referência metodológica de aprendizagem baseada em projetos adotada pela disciplina. O tratamento dos dados pessoais dos participantes, em especial a localização, que é dado sensível pelo contexto de uso, observa a Lei nº 13.709/2018 (Lei Geral de Proteção de Dados) e a Lei nº 10.741/2003 (Estatuto da Pessoa Idosa), que fundamenta o dever de proteção e o direito à autonomia da pessoa idosa. Essa observância não é acessória: é o que distingue a solução proposta dos dispositivos importados que enviam a localização de idosos brasileiros a servidores fora do país sem base legal definida.

---

## Referências

ALMEIDA, Rodrigo Maximiniano A. **Programação de sistemas embarcados: desenvolvendo software para microcontroladores em linguagem C**. São Paulo: Grupo GEN, 2016.

BENDER, William N. **Aprendizagem baseada em projetos: educação diferenciada para o século XXI**. Porto Alegre: Penso, 2015.

BRASIL. **Lei nº 10.741, de 1º de outubro de 2003**. Dispõe sobre o Estatuto da Pessoa Idosa.

BRASIL. **Lei nº 13.709, de 14 de agosto de 2018**. Lei Geral de Proteção de Dados Pessoais (LGPD).

CONSELHO MUNICIPAL DO IDOSO DE RIBEIRÃO PRETO. **Organizações da sociedade civil cadastradas**. Ribeirão Preto: Secretaria da Assistência Social, 2026.

INSTITUTO BRASILEIRO DE GEOGRAFIA E ESTATÍSTICA. **Projeções da população do Brasil e unidades da federação por sexo e idade: 2000-2070**. Rio de Janeiro: IBGE, 2024.

MONK, Simon. **Programação com Arduino: começando com sketches**. 2. ed. Porto Alegre: Bookman, 2017.

SILVA, A. et al. Acidentes por quedas na população idosa: análise de tendência temporal de 2000 a 2020 e o impacto econômico estimado no sistema de saúde brasileiro em 2025. **Ciência & Saúde Coletiva**, v. 28, n. 11, p. 3101-3110, nov. 2023. DOI 10.1590/1413-812320232811.15722022.

SUCERQUIA, A.; LÓPEZ, J. D.; VARGAS-BONILLA, J. F. SisFall: a fall and movement dataset. **Sensors**, v. 17, n. 1, p. 198, 2017.

ZANCO, Wagner da Silva. **Microcontroladores PIC18 com linguagem C: uma abordagem prática e objetiva**. São Paulo: Érica, 2010.

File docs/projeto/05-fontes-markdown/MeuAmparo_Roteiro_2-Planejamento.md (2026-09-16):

# MeuAmparo — Roteiro de Extensão

# 2. Planejamento e desenvolvimento do projeto

Entrega prevista: **23/set/2026** · Seminário de planejamento: **16/set/2026**

---

## 2.1 Plano de trabalho

### Cronograma

```mermaid
gantt
    title MeuAmparo — cronograma 2026.2
    dateFormat YYYY-MM-DD
    axisFormat %d/%m

    section Entregas
    Roteiro 1a parte (1.1 a 1.5)       :milestone, m1, 2026-09-09, 0d
    Seminario de planejamento          :milestone, m2, 2026-09-16, 0d
    Roteiro 2a parte (2.1 a 2.5)       :milestone, m3, 2026-09-23, 0d
    Seminario de desenvolvimento       :milestone, m4, 2026-10-28, 0d
    Roteiro 3a parte e seminario final :milestone, m5, 2026-11-25, 0d

    section Parte interessada
    Contato e formalizacao             :a1, 2026-09-09, 14d
    Visita de escuta e entrevista      :a2, 2026-09-16, 14d
    Validacao da proposta              :a3, 2026-10-14, 7d
    Oficina de montagem com a equipe   :a4, 2026-11-11, 7d
    Avaliacao de reacao                :a5, 2026-11-18, 7d

    section Hardware
    Compra e importacao dos componentes :b1, 2026-09-09, 42d
    Requisitos e escolha do MCU         :b2, 2026-09-23, 14d
    Arquitetura e diagrama de blocos    :b3, 2026-09-30, 14d
    Case em 3D                          :b4, 2026-10-21, 14d
    Montagem do circuito                :b5, 2026-10-28, 14d

    section Software
    Firmware: deteccao de queda        :c1, 2026-10-07, 28d
    Firmware: GPS e comunicacao        :c2, 2026-10-14, 28d
    Backend e painel de alertas        :c3, 2026-10-14, 28d
    Simulacao e testes unitarios       :c4, 2026-10-28, 14d
    Teste de integracao                :c5, 2026-11-11, 7d

    section Documentacao
    Relato coletivo                    :d1, 2026-11-11, 14d
    Relatos individuais                :d2, 2026-11-11, 14d
```

### Ações, prazos, responsáveis e acompanhamento

| # | Ação | Período | Responsável | Como acompanhamos |
|---|---|---|---|---|
| 1 | Entrega do Roteiro, 1ª parte (1.1 a 1.5) | 09/set | **[A]** | PDF postado na SAVA |
| 2 | Contato e formalização com a parte interessada | 09 a 23/set | **[A]** | Carta de apresentação e carta de autorização assinadas |
| 3 | Compra e importação dos componentes | 09/set a 21/out | **[B]** | Código de rastreio e chegada registrada |
| 4 | Visita de escuta e entrevista na instituição | 16 a 30/set | **[A]** e **[E]** | Roteiro de entrevista preenchido, fotos |
| 5 | Seminário de planejamento | 16/set | todos | Apresentação e feedback do professor |
| 6 | Entrega do Roteiro, 2ª parte (2.1 a 2.5) | 23/set | **[E]** | PDF postado na SAVA |
| 7 | Levantamento de requisitos e escolha do microcontrolador | 23/set a 07/out | **[B]** | Tabela comparativa de MCUs, decisão registrada |
| 8 | Arquitetura, diagrama de blocos e fluxograma | 30/set a 14/out | **[B]** e **[C]** | Diagramas versionados no repositório |
| 9 | Validação da proposta com a parte interessada | 14 a 21/out | **[A]** | Ata da reunião e aceite registrado |
| 10 | Firmware: leitura do IMU e detecção de queda | 07/out a 04/nov | **[C]** | Commits no Git, testes passando |
| 11 | Firmware: GPS, conectividade e envio do alerta | 14/out a 11/nov | **[C]** | Commits no Git, alerta chegando |
| 12 | Backend e painel de alertas | 14/out a 11/nov | **[D]** | Painel no ar, alerta visível |
| 13 | Modelagem e impressão do case | 21/out a 04/nov | **[B]** | STL no repositório, peça impressa |
| 14 | Simulação e testes das funções individuais | 28/out a 11/nov | **[C]** | Registro da simulação no SimulIDE |
| 15 | Seminário de desenvolvimento | 28/out | todos | Apresentação e feedback |
| 16 | Montagem do circuito e teste de integração | 28/out a 18/nov | **[B]** e **[C]** | Vídeo do teste de queda simulada |
| 17 | Oficina de montagem e configuração com a equipe | 11 a 18/nov | **[A]** e **[E]** | Cronômetro do exercício, fotos |
| 18 | Avaliação de reação da parte interessada | 18 a 25/nov | **[A]** | Formulário respondido e vídeo do depoimento |
| 19 | Relato coletivo e relatos individuais | 11 a 25/nov | todos | Texto revisado pelo grupo |
| 20 | Entrega final e seminário de avaliação | 25/nov | todos | PDF postado na SAVA |

**Oportunidade paralela:** o III EPEI recebe submissões até **21/set**, divulga aprovados em **24/set** e apresenta em **29/set**. O resumo pede de 2.000 a 5.000 caracteres sem espaços, em texto puro, sem tabelas nem figuras, com 3 a 5 palavras-chave. O material das seções 1.1 a 1.5 já cobre quase tudo o que o resumo exige.

### Marcos que não podem escorregar

Três datas seguram todo o resto. **23/set**, porque sem a parte interessada formalizada não há como escrever 2.2. **14/out**, porque a validação da proposta precisa acontecer antes de o firmware estar pronto, senão não é validação, é homologação do que já foi feito. **18/nov**, porque a avaliação de reação precisa de uma semana de folga antes da entrega final.

---

## 2.2 Forma de envolvimento do público participante

### No planejamento

O problema não foi levado pronto à instituição. A primeira visita é de escuta: uma conversa com a coordenação e com os cuidadores sobre a rotina do local, o histórico de quedas e episódios de desorientação nos últimos meses, o que já se usa hoje para lidar com isso e o que falha. Só depois dessa conversa o grupo prioriza qual problema atacar e apresenta uma proposta.

A proposta volta à instituição para validação antes de qualquer linha de firmware ser escrita, na ação 9 do cronograma. Se a equipe apontar que o formato de pendente não funciona para o público deles, ou que o alerta precisa chegar de outro jeito, o projeto muda ali, não no fim.

### No desenvolvimento

Os cuidadores participam de duas formas concretas. Primeiro, definindo o comportamento do alerta: quem recebe, em que ordem, quanto tempo o dispositivo espera antes de disparar. São decisões de operação, e quem opera é a equipe, não o grupo. Segundo, testando: as quedas simuladas para calibrar o algoritmo são feitas por voluntários da equipe, com o dispositivo no corpo, e o retorno deles sobre peso, incômodo e posição alimenta o ajuste do case.

### Na avaliação

Três instrumentos, todos com o público como sujeito e não como observado:

1. **Teste assistido de detecção.** Voluntários simulam quedas em ambiente controlado, com colchonete. Registramos acertos, falhas e alarmes falsos.
2. **Exercício de autonomia.** Um membro da equipe configura um dispositivo do zero, sem intervenção do grupo, cronometrado. É a verificação direta do objetivo 3.
3. **Avaliação de reação.** Formulário aplicado à coordenação e aos cuidadores, com depoimento em vídeo de quem quiser falar.

### Estratégias de mobilização

O primeiro contato é feito pessoalmente, com a carta de apresentação da Estácio em mãos, e não por e-mail. Instituição pequena responde a quem aparece. As reuniões são marcadas no horário que couber na rotina da equipe, não na do grupo. Cada encontro termina com o combinado seguinte já marcado. E o grupo devolve alguma coisa em cada visita, nem que seja o resumo da conversa anterior por escrito, para que a relação não seja só de extração de informação.

### Registros

Todo encontro gera evidência: fotos da visita com autorização de uso de imagem, ata ou resumo enviado à instituição por mensagem, formulários preenchidos, capturas de tela das conversas, vídeo dos testes e da oficina. As evidências são anexadas ao roteiro e organizadas por data.

> **[PENDÊNCIA]** Providenciar o termo de autorização de uso de imagem antes da primeira visita.

---

## 2.3 Grupo de trabalho

> **[PREENCHER]** Grupo em formação. Os papéis abaixo são a proposta de divisão; substituir as letras pelos nomes e matrículas.

| Papel | Responsabilidades | Atividades no cronograma |
|---|---|---|
| **[A]** — Coordenação e relação com a parte interessada | Manter o contato com a instituição, conduzir as visitas, cuidar da documentação de formalização e das evidências | 1, 2, 4, 9, 17, 18 |
| **[B]** — Hardware | Seleção e justificativa do microcontrolador, compra dos componentes, montagem do circuito, modelagem e impressão do case | 3, 7, 8, 13, 16 |
| **[C]** — Firmware | Desenvolvimento em linguagem C: leitura do IMU, algoritmo de detecção, GPS, comunicação, simulação e testes | 8, 10, 11, 14, 16 |
| **[D]** — Backend e interface | API, recebimento dos alertas, painel web de monitoramento e histórico | 12 |
| **[E]** — Documentação | Redação do roteiro, organização das evidências, preparação das apresentações dos seminários | 4, 6, 19 |

Todos os integrantes participam dos quatro seminários e escrevem o próprio relato individual. As habilidades técnicas exigidas pela disciplina — distinção entre tipos de microcontroladores, programação em C, uso de periféricos internos e externos, protocolos I²C, UART e SPI, e interrupções — são demonstradas por todos, e não apenas por quem tem o papel de firmware. Para isso, as revisões de código são feitas em dupla e cada integrante apresenta pelo menos uma parte técnica nos seminários.

---

## 2.4 Metas, critérios e indicadores

### Objetivo 1 — Desenvolver o dispositivo de detecção e alerta

| Etapa | Critério | Indicador |
|---|---|---|
| Escolha do microcontrolador | Decisão justificada por requisitos, não por hábito | Tabela comparativa com ao menos 4 famílias, avaliadas em consumo, tamanho, custo, memória e periféricos |
| Detecção de queda | O algoritmo distingue queda de atividade cotidiana | **Ao menos 90% das quedas simuladas detectadas** e **menos de 1 alarme falso por dia** por dispositivo |
| Localização | O alerta informa onde a pessoa está | Coordenada obtida em ambiente aberto; em ambiente fechado, identificação por rede conhecida |
| Alerta de área segura | Saída da área gera aviso em tempo útil | **Alerta emitido em até 2 minutos** após cruzar o limite |
| Autonomia | O dispositivo cobre um dia de uso | **Mínimo de 8 horas** por carga, medido em uso contínuo |
| Custo | Replicável por uma organização social | **Até R$ 500 por unidade**, com nota de compra |

### Objetivo 2 — Documentar como projeto aberto

| Etapa | Critério | Indicador |
|---|---|---|
| Publicação | Tudo o que é necessário para replicar está disponível | Repositório público com esquema, lista de materiais com fornecedores, modelo do case, código-fonte e licença GNU GPL v3 |
| Roteiro de montagem | Qualquer pessoa com o kit consegue montar | Documento com passo a passo e fotos de cada etapa |
| Verificação | A documentação basta sem apoio verbal | Uma pessoa de fora do grupo monta uma unidade seguindo só o documento |

### Objetivo 3 — Capacitar a equipe da instituição

| Etapa | Critério | Indicador |
|---|---|---|
| Oficina | A equipe recebeu formação prática | Oficina realizada, com lista de presença e registro fotográfico |
| Autonomia de configuração | A equipe opera sem o grupo | **Um membro da equipe configura um dispositivo do zero, sozinho, em menos de 15 minutos** |
| Satisfação | A solução atende quem vai usar | **Nota mínima 4 em 5** na avaliação de reação, com depoimento em vídeo |

---

## 2.5 Recursos previstos

### Materiais — uma unidade de protótipo

| Item | Especificação | Custo | Fonte do recurso |
|---|---|---|---|
| Placa principal | LilyGO T-A7670G R2 com GPS: ESP32-WROVER, 4G LTE Cat-1, GNSS, carregador e suporte de bateria, com antenas 4G e GPS | R$ 169 | grupo |
| Sensor inercial | MPU6050, acelerômetro e giroscópio de 3 eixos | R$ 28 | grupo |
| Bateria | 18650 recarregável, 3500 mAh | R$ 55 | grupo |
| Interface | Botão de pânico, buzzer, LED, barras de pinos, fios e parafusos | R$ 25 | grupo |
| Case | Impressão em PETG e cordão com engate de segurança | R$ 30 | grupo |
| Placa portadora | PCB própria, lote de 5 | R$ 12/un | grupo |
| Importação | Frete e ICMS | R$ 100 | grupo |
| **Total** | | **R$ 419 por unidade** | |
| Conectividade | Chip de dados M2M | mensalidade a definir | a negociar com a operadora ou com a instituição |

Compras internacionais de até US$ 50 estão isentas do Imposto de Importação federal desde maio de 2026, incidindo apenas o ICMS estadual. A placa fica abaixo desse limite.

### Institucionais

- Laboratório e impressora 3D da Estácio Ribeirão Preto. Alternativa sem custo de fabricação: caixa plástica comercial, cerca de R$ 25.
- Espaço e horário da instituição parceira para as visitas, testes e oficina.
- Orientação do Prof. Omar Sacilotto Donaires.

### Humanos

- Horas de trabalho dos integrantes do grupo, distribuídas conforme a seção 2.3.
- Tempo da coordenação e dos cuidadores da instituição nos encontros, testes e avaliação.

### Estratégias de contenção de custo

Todo o ferramental é livre e sem licença: **ESP-IDF** para o firmware, **SimulIDE** para a simulação, **FreeCAD ou OpenSCAD** para o case e **Git** para o versionamento. O Roteiro de Extensão aceita desenvolvimento e teste por simulação computacional, o que significa que o projeto não depende financeiramente da compra do hardware para ser entregue. A montagem física é um ganho adicional, custeado pelo grupo, e não um requisito de aprovação.

---

# Apêndice — Roteiro do seminário de planejamento (16/set)

**Formato:** grupos sorteados, **3 minutos por integrante**. Cada um explica **qual foi sua contribuição** ao trabalho até aqui e **o que aprendeu**. A nota do seminário compõe a nota da entrega de 23/set.

### Fio condutor do grupo, em três frases

> Idosos que caem sozinhos ficam horas sem socorro, e quem tem demência pode sair e não saber voltar. Existe dispositivo no mercado, mas ele cobra mensalidade, manda os dados para fora do país e é configurado por comando SMS que ninguém consegue usar. Nosso projeto entrega o mesmo resultado como kit aberto de até R$ 500, que a instituição monta e opera sozinha.

### Divisão sugerida das falas

| Quem | Contribuição a relatar | Aprendizado a destacar |
|---|---|---|
| **[A]** | Contato com a instituição, escuta e formalização | O problema real não era o que imaginávamos antes de conversar com a equipe |
| **[B]** | Levantamento de componentes e custo | Comprar módulo avulso no Brasil custa mais que a placa integrada importada, e isso muda o projeto |
| **[C]** | Estudo do algoritmo de detecção | A queda tem quatro estágios, e é a imobilidade posterior que separa a queda de sentar bruscamente |
| **[D]** | Arquitetura do alerta e dos dados | Localização de idoso é dado sensível, e a LGPD entra no projeto como requisito técnico |
| **[E]** | Estado da arte e documentação | Existem dezenas de projetos abertos parecidos, e mapear o que eles não fazem foi o que definiu nosso recorte |

### Três perguntas prováveis do professor

**"Por que ESP32 e não outro microcontrolador?"** — Porque os requisitos pedem Wi-Fi e Bluetooth integrados, potência para o algoritmo de detecção, custo baixo e disponibilidade nacional. A comparação formal com outras famílias é a entrega de 07/out.

**"E se a placa não chegar?"** — O roteiro aceita simulação em software livre. O SimulIDE cobre a exigência, e o hardware físico é um ganho, não um requisito.

**"Qual é a parte interessada?"** — **[PREENCHER com a resposta honesta do estágio em que o contato estiver na data.]**

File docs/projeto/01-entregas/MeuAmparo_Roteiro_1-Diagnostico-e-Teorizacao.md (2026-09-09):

# 1. Diagnóstico e teorização

## 1.1 Identificação das partes interessadas e parceiros

O MeuAmparo é uma proposta de dispositivo vestível para pessoas idosas, desenvolvida por Luis Gustavo Moda e Isabelly Vitoria na disciplina Programação de Microcontroladores, da Estácio Ribeirão Preto. Pretendemos trabalhar com uma instituição sem fins lucrativos do município e sua equipe de cuidadores. Em 9 de setembro de 2026, a parceria ainda está em prospecção, sem acordo formalizado ou visita de escuta registrada.

Casa do Vovô, Lar Padre Euclides e Lar do Vovô Albano estão entre as candidatas do levantamento do grupo. A escolha depende da demanda apresentada pela entidade e da disponibilidade para os encontros.

O público pretendido é de pessoas com 60 anos ou mais, especialmente aquelas que precisam de acompanhamento por histórico de quedas ou episódios de desorientação. A faixa inicial de 15 a 40 pessoas é uma estimativa de planejamento. Ainda não dispomos de informações locais sobre escolaridade, renda, gênero ou necessidades de apoio. A caracterização dos participantes depende da instituição escolhida.

Cuidadores e coordenação participarão da definição do fluxo de atendimento aos alertas; familiares de referência poderão ser envolvidos conforme a rotina do local. A formalização da parceria e as autorizações de participação e de imagem antecedem as atividades que delas dependem.

## 1.2 Problemática e/ou problemas identificados

Uma queda sem testemunhas pode deixar a pessoa sem condições de pedir ajuda. Partimos desse problema para estudar um dispositivo que identifique movimentos compatíveis com uma queda e avise um cuidador. O botão de pânico atende a outra situação: quando a pessoa consegue pedir ajuda por conta própria. A proposta também inclui localização e aviso de saída de uma área segura, cuja utilidade precisa ser discutida com a instituição.

As projeções do IBGE divulgadas em 2024 mostram que a população com 60 anos ou mais passou de 8,7% em 2000 para 15,6% em 2023, cerca de 33 milhões de pessoas. Para 2070, a projeção é de 37,8%. Esses dados dimensionam o envelhecimento no país, mas não descrevem o público de uma instituição específica.

Novaes et al. (2023) analisaram internações e custos relacionados às quedas entre 2000 e 2020. No estado de São Paulo, encontraram crescimento médio anual de 4,3% nas internações e de 8,5% nos custos totais. O estudo projetou cerca de 150 mil internações e R$ 260 milhões em custos para o SUS em 2025.

Nesta etapa, o diagnóstico é documental; a escuta da instituição vai confirmar ou ajustar a demanda. A pergunta que levaremos é: como avisar os cuidadores sobre uma possível queda ou afastamento, com localização disponível e custo de manutenção compatível com sua rotina? A escuta deve esclarecer quais ocorrências preocupam a equipe, como o atendimento funciona hoje e se as funções propostas são úteis.
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

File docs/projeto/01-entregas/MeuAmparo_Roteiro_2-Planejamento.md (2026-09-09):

# 2. Planejamento e desenvolvimento do projeto

## 2.1 Plano de trabalho

O planejamento organiza o desenvolvimento do MeuAmparo até novembro de 2026. A parceria ainda está em prospecção. As atividades de campo dependem do acordo com a instituição; os períodos abaixo são previsões de trabalho.
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

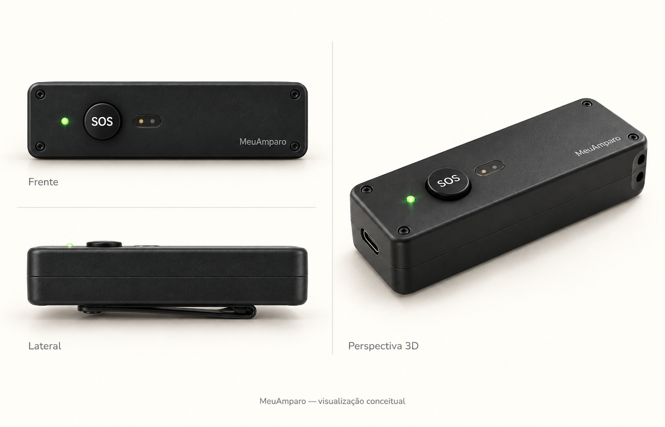
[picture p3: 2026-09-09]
docs/projeto/03-hardware/renders/case_preto_vistas_conceituais.png

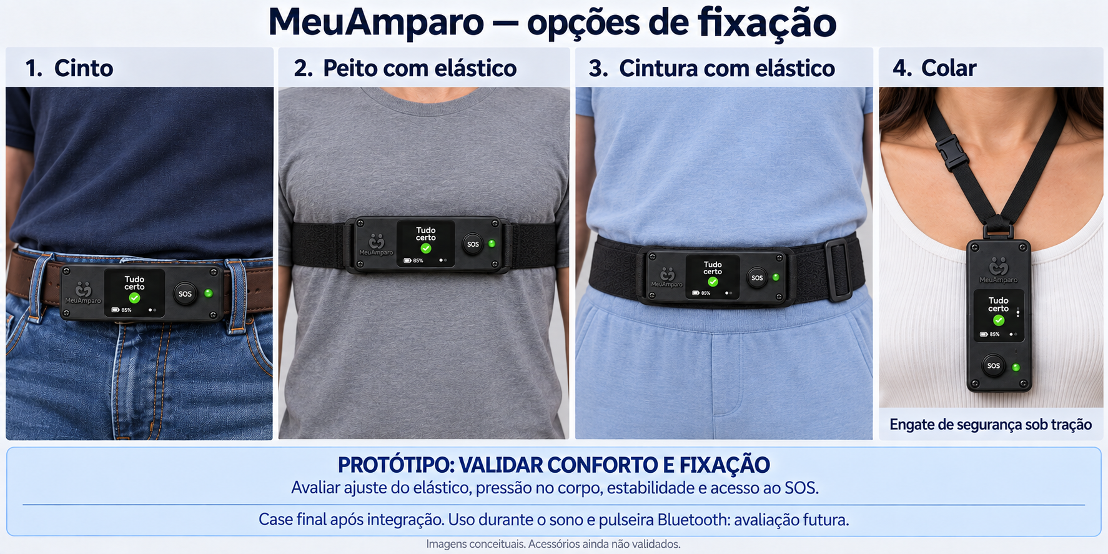
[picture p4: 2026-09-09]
docs/projeto/03-hardware/renders/touch_fixacoes_elastico_colar.png

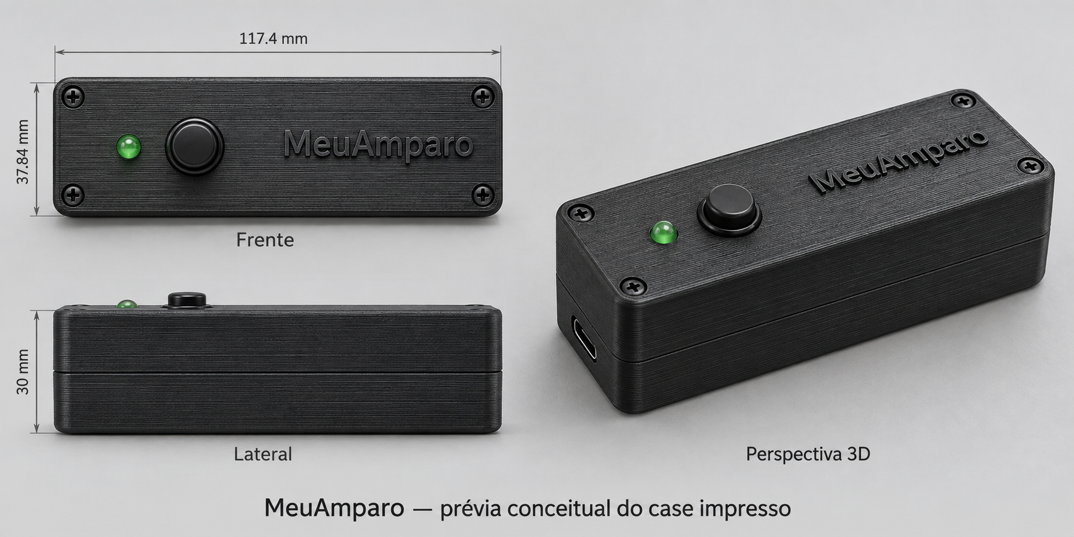
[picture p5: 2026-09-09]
docs/projeto/03-hardware/renders/case_preto_alto_relevo.png

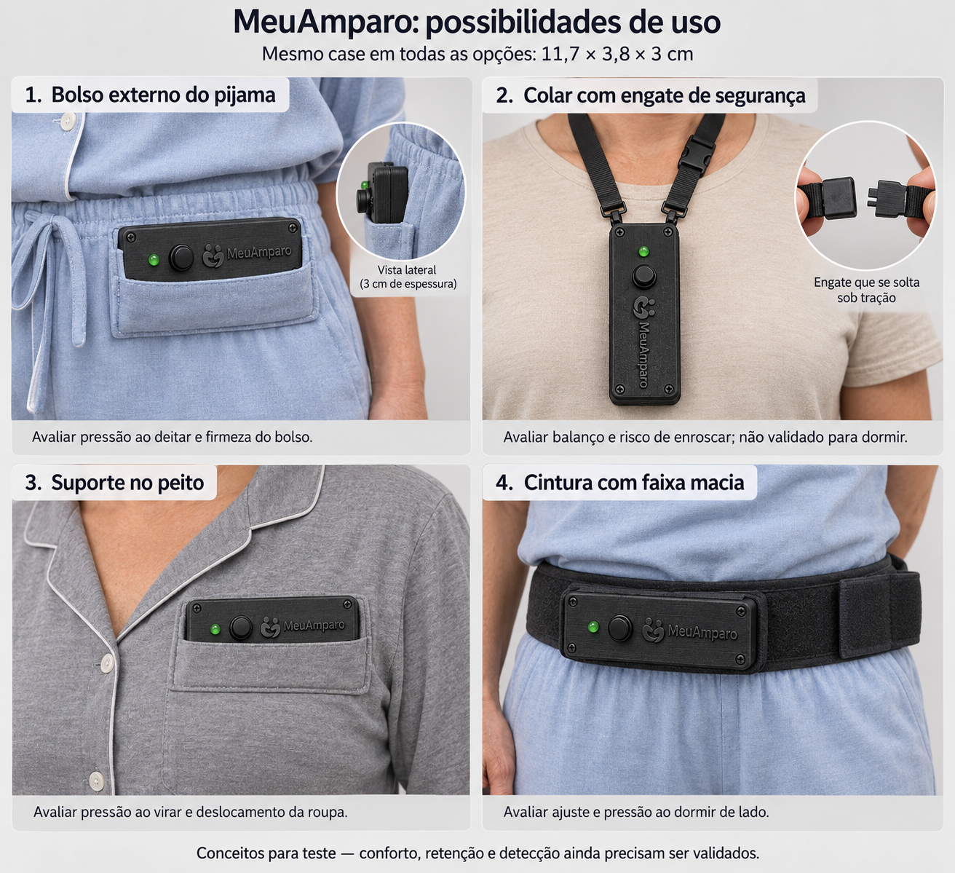
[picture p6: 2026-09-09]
docs/projeto/03-hardware/renders/possibilidades_fixacao.png

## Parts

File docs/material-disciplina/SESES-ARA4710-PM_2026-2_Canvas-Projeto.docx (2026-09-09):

Título:

Grupo / Responsabilidades

Recursos previstos

Metas, critérios ou indicadores

Estratégia de envolvimento do público participante

Plano de trabalho

Referencial teórico

Problemática e/ou problema

Justificativa

Objetivos/resultados/efeitos

Partes interessadas e parceiros

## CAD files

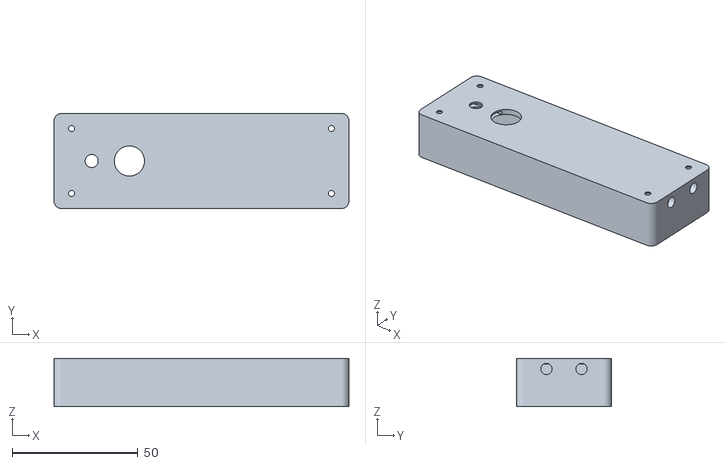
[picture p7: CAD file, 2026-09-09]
docs/projeto/03-hardware/case/meuamparo_case_tampa.stl
117.4 x 37.8 x 19.2

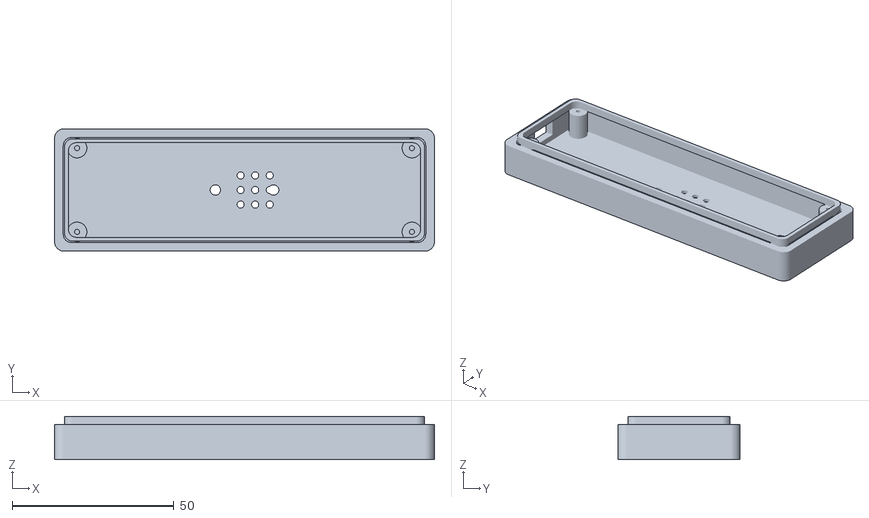
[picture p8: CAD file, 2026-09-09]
docs/projeto/03-hardware/case/meuamparo_case_base.stl
117.4 x 37.8 x 13.3

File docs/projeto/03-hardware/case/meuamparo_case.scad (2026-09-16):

// =====================================================================
//  MeuAmparo - case do dispositivo de deteccao de queda
//  Projeto aberto - licenca GNU GPL v3
//  Placa alvo: Waveshare ESP32-S3-SIM7670G-4G (110 x 30,44 mm)
//
//  COMO USAR
//  1. Meça a placa com paquímetro quando ela chegar e ajuste os
//     parâmetros marcados com "MEDIR". Só eles precisam mudar.
//  2. Renderize e exporte: openscad -o base.stl -D peca=1 este.scad
//                          openscad -o tampa.stl -D peca=2 este.scad
//  3. Envie os dois STL para o serviço de impressão.
// =====================================================================

peca = 0;          // 0 = conjunto aberto (visualizacao) | 1 = base | 2 = tampa
$fn = 48;

// ---------------------------------------------------------------------
// 1. PLACA  (valores do datasheet; os marcados MEDIR sao estimativa)
// ---------------------------------------------------------------------
pcb_comp        = 110.00;   // datasheet Waveshare
pcb_larg        =  30.44;   // datasheet Waveshare
pcb_esp         =   1.60;   // padrao
alt_sup_18650   =  19.50;   // MEDIR - altura do suporte da bateria sobre a placa
alt_inferior    =   3.00;   // MEDIR - altura dos componentes sob a placa

// Posicoes ao longo do comprimento, medidas da borda esquerda da placa
pos_usb         =   8.00;   // MEDIR - centro do conector USB-C
pos_leds_placa  =  22.00;   // MEDIR - centro do grupo de LEDs da placa
pos_antena_gnss =  92.00;   // MEDIR - centro da antena ceramica GNSS

// ---------------------------------------------------------------------
// 2. CAIXA
// ---------------------------------------------------------------------
folga    = 1.50;   // espaco livre entre placa e parede interna
parede   = 2.20;   // espessura da parede (3 perimetros a 0,4 mm + margem)
raio     = 3.00;   // arredondamento das quinas
lab_alt  = 2.50;   // altura do labio de encaixe entre base e tampa

int_comp = pcb_comp + 2*folga;
int_larg = pcb_larg + 2*folga;
int_alt  = alt_inferior + pcb_esp + alt_sup_18650 + folga;

ext_comp = int_comp + 2*parede;   // ~117,4 mm
ext_larg = int_larg + 2*parede;   // ~ 37,8 mm
ext_alt  = int_alt  + 2*parede;   // ~ 30,0 mm

alt_base = alt_inferior + pcb_esp + parede + 4;  // altura da bandeja inferior

// ---------------------------------------------------------------------
// 3. ABERTURAS
// ---------------------------------------------------------------------
usb_larg      =  9.50;   // recorte do USB-C
usb_alt       =  4.20;
bot_diam      = 12.00;   // botao de panico
bot_pos       = 30.00;   // centro do botao, a partir da esquerda
led_diam      =  5.20;   // LED RGB do projeto
led_pos       = 15.00;   // centro do LED, a partir da esquerda
jan_leds_c    = 22.00;   // janela sobre os LEDs da placa
jan_leds_l    =  7.00;
jan_leds_esp  =  0.80;   // parede fina: translucida quando impressa
buzzer_pos    = 62.00;   // centro da matriz de furos do buzzer
buzzer_furo   =  2.20;
ant_janela_c  = 26.00;   // parede fina sobre a antena GNSS
ant_janela_l  = 26.00;
ant_janela_esp=  1.20;   // MENOR parede possivel: o GNSS precisa "ver" o ceu
cordao_diam   =  4.50;   // ilhoses para o cordao

// =====================================================================
//  MODULOS
// =====================================================================

module caixa_ext(h) {
    hull() for (x=[raio, ext_comp-raio], y=[raio, ext_larg-raio])
        translate([x,y,0]) cylinder(h=h, r=raio);
}

module cavidade(h) {
    translate([parede, parede, parede])
        hull() for (x=[raio, int_comp-raio], y=[raio, int_larg-raio])
            translate([x,y,0]) cylinder(h=h, r=raio-0.5);
}

// pilares de fixacao nos 4 cantos - parafuso M2 auto-atarraxante
module pilares(h, furo) {
    for (x=[7, ext_comp-7], y=[6, ext_larg-6])
        translate([x,y,parede]) difference() {
            cylinder(h=h, d=6);
            translate([0,0,-0.1]) cylinder(h=h+0.2, d=furo);
        }
}

module furos_buzzer() {
    for (i=[-1:1], j=[-1:1])
        translate([buzzer_pos + i*4.5, ext_larg/2 + j*4.5, -1])
            cylinder(h=parede+2, d=buzzer_furo);
}

module ilhoses_cordao() {
    for (y=[ext_larg/2 - 7, ext_larg/2 + 7])
        translate([ext_comp-1, y, ext_alt/2]) rotate([0,90,0])
            cylinder(h=8, d=cordao_diam, center=true);
}

// ---------------------------------------------------------------------
//  BASE  - abriga a placa, o USB, o buzzer e o clipe de cinto
// ---------------------------------------------------------------------
module base() {
    difference() {
        union() {
            difference() {
                caixa_ext(alt_base);
                cavidade(alt_base);
                // recorte do USB-C na lateral esquerda
                translate([-1, ext_larg/2 - usb_larg/2, parede + alt_inferior - 1])
                    cube([parede+2, usb_larg, usb_alt+2]);
                furos_buzzer();
            }
            pilares(alt_base - parede, 1.6);
            // labio de encaixe
            translate([parede+0.4, parede+0.4, alt_base])
                difference() {
                    hull() for (x=[raio, int_comp-raio-0.8], y=[raio, int_larg-raio-0.8])
                        translate([x,y,0]) cylinder(h=lab_alt, r=raio-0.5);
                    translate([1.2,1.2,-0.1])
                        hull() for (x=[raio, int_comp-raio-3.2], y=[raio, int_larg-raio-3.2])
                            translate([x,y,0]) cylinder(h=lab_alt+0.2, r=raio-0.5);
                }
        }
        // rebaixo e furos M3 para o clipe de cinto, na face inferior
        translate([ext_comp/2 - 15, ext_larg/2 - 9, -0.1]) cube([30, 18, 1.2]);
        for (x=[ext_comp/2 - 9, ext_comp/2 + 9])
            translate([x, ext_larg/2, -1]) cylinder(h=parede+2, d=3.2);
    }
}

// ---------------------------------------------------------------------
//  TAMPA - leva o botao, o LED do projeto, a janela dos LEDs da placa
//          e a parede fina sobre a antena GNSS
// ---------------------------------------------------------------------
module tampa() {
    alt_t = ext_alt - alt_base;
    difference() {
        union() {
            difference() {
                caixa_ext(alt_t);
                translate([parede, parede, -0.1])
                    hull() for (x=[raio, int_comp-raio], y=[raio, int_larg-raio])
                        translate([x,y,0]) cylinder(h=alt_t-parede+0.1, r=raio-0.5);
            }
            // rebaixo interno da antena: deixa so 1,2 mm de plastico
            translate([pos_antena_gnss - ant_janela_c/2, ext_larg/2 - ant_janela_l/2, alt_t - parede])
                cube([ant_janela_c, ant_janela_l, 0.01]);
        }
        // botao de panico
        translate([bot_pos, ext_larg/2, -1]) cylinder(h=alt_t+2, d=bot_diam);
        // LED RGB do projeto
        translate([led_pos, ext_larg/2, -1]) cylinder(h=alt_t+2, d=led_diam);
        // janela translucida sobre os LEDs da placa
        translate([pos_leds_placa - jan_leds_c/2, ext_larg/2 - jan_leds_l/2, alt_t - parede])
            cube([jan_leds_c, jan_leds_l, parede - jan_leds_esp + 0.1]);
        // desbaste sobre a antena GNSS
        translate([pos_antena_gnss - ant_janela_c/2, ext_larg/2 - ant_janela_l/2, alt_t - parede])
            cube([ant_janela_c, ant_janela_l, parede - ant_janela_esp + 0.1]);
        // passagem dos parafusos
        for (x=[7, ext_comp-7], y=[6, ext_larg-6])
            translate([x,y,-1]) {
                cylinder(h=alt_t+2, d=2.4);
                translate([0,0,alt_t-1.4]) cylinder(h=2, d=4.6);   // rebaixo da cabeca
            }
        ilhoses_cordao();
    }
}

// =====================================================================
//  SAIDA
// =====================================================================
if (peca == 1) base();
else if (peca == 2) tampa();
else {
    base();
    translate([0, ext_larg + 12, 0]) tampa();
}

echo(str("EXTERNO: ", ext_comp, " x ", ext_larg, " x ", ext_alt, " mm"));

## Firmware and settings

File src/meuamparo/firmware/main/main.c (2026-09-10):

// Demo mínima: pisca o LED de status. Serve para provar a cadeia inteira antes de
// existir sensor ou alerta — ESP-IDF compila, binário sobe no Wokwi, pino responde.
// Quando o detector de queda entrar, este LED vira o indicador de alerta.

#include "driver/gpio.h"
#include "esp_log.h"
#include "freertos/FreeRTOS.h"
#include "freertos/task.h"

// GPIO2 no devkit ESP32-S3 e no diagrama do Wokwi. A placa definitiva ainda está
// em aberto na documentação, então o pino vive aqui e não espalhado pelo código.
#define MA_LED_GPIO GPIO_NUM_2

// Meio segundo aceso, meio apagado: rápido o bastante para ver na apresentação,
// lento o bastante para contar no vídeo.
#define MA_BLINK_PERIOD_MS 500

static const char *TAG = "meuamparo";

void app_main(void)
{
    gpio_config_t led = {
        .pin_bit_mask = 1ULL << MA_LED_GPIO,
        .mode = GPIO_MODE_OUTPUT,
        .pull_up_en = GPIO_PULLUP_DISABLE,
        .pull_down_en = GPIO_PULLDOWN_DISABLE,
        .intr_type = GPIO_INTR_DISABLE,
    };
    ESP_ERROR_CHECK(gpio_config(&led));

    ESP_LOGI(TAG, "demo do LED iniciada no GPIO%d", MA_LED_GPIO);

    int level = 0;
    while (1) {
        level = !level;
        gpio_set_level(MA_LED_GPIO, level);
        ESP_LOGI(TAG, "led=%d", level);
        vTaskDelay(pdMS_TO_TICKS(MA_BLINK_PERIOD_MS));
    }
}

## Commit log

2026-09-09 Inicia repositório com instruções para agentes
    Adiciona .gitignore para o .DS_Store do macOS e os arquivos de lock
    temporário do Word, e as instruções de trabalho em .agents/workflow/.
    AGENTS.md e CLAUDE.md são ponteiros para o index.md.
2026-09-09 Adiciona material da disciplina ARA4710
    Aulas 01 a 05, roteiro de extensão, carta de apresentação, Canvas-Projeto
    e edital do III EPEI. Material recebido da Estácio, não editar.
2026-09-09 Adiciona entregas e fontes de trabalho do projeto
    Roteiros 1 e 2, canvas de apresentação, levantamento de instituições de
    Ribeirão Preto, case em OpenSCAD com os dois STL, cotação, figuras e as
    versões em Markdown dos documentos que também existem em Word.
    [meuamparo_case.scad, meuamparo_case_base.stl, meuamparo_case_tampa.stl]
2026-09-10 Ignora a pasta src/samples
    Exemplos de aula em PIC, usados para experimentar o PICSimLab. Não fazem
    parte do MeuAmparo e não precisam ir para o repositório.
    Claude-Session: https://claude.ai/code/session_015GmhDMfkkgfucV2q8rAHvg
2026-09-10 Adiciona o esqueleto do código em src/meuamparo
    Quatro pastas com fronteira rígida entre elas: core em C puro, firmware
    ESP-IDF, simulador Wokwi e testes de host. A separação existe para medir a
    meta de detecção rodando o algoritmo contra traces no notebook, sem placa.
    Hoje só core e test têm conteúdo: a magnitude de aceleração e um teste que
    passa com make test. As demais pastas têm README descrevendo o destino.
    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
2026-09-10 Adiciona o Gantt do cronograma do projeto
    Gerado em SVG a partir da Tabela 2 do Roteiro 2, com as 13 atividades
    previstas e os cinco marcos da disciplina. O PNG é a mesma figura em 2400 px,
    para o caso de o Word não aceitar o vetorial.
    O Gantt anterior mostrava importação da placa e duas barras de firmware
    repetidas, atividades que não constam mais do planejamento.
    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
2026-09-10 Reorganiza docs/ para quem chega ao repositório sem contexto
    O nome do arquivo repetia o nome do projeto em 32 arquivos, e a pasta do
    material da disciplina estava escrita errada. Agora:
    - material estácio vira material-disciplina, sem o erro de digitação
    - o prefixo MeuAmparo_ sai de todos os nomes
    - 01-entregas separa docx, md e pdf, com as figuras ao lado
    - 06-Marketing vira 04-identidade-visual, que descreve o que tem dentro
    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
2026-09-10 Adiciona o README de docs/projeto
    Índice da pasta: entregas com prazo e pontos, calendário da disciplina, o que
    guarda cada subpasta e o que continua em aberto.
    Em Markdown porque o GitHub renderiza a página; o 00-LEIA-ME.docx que fazia
    esse papel só aparece como download para quem abre o repositório pelo
    navegador.
    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
2026-09-10 Atualiza os caminhos citados nas instruções e no README
    A logo do README apontava para docs/Logomarca, que deixou de existir na
    reorganização, e aparecia quebrada na primeira linha da página do repositório.
    As instruções em .agents descreviam a árvore antiga inteira, incluindo pastas
    que não existem mais. Como elas orientam agentes de IA, desatualizadas geram
    trabalho errado.
    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
2026-09-16 Ignora a pasta tmp
    Roteiros de ensaio e rascunhos que não fazem parte da entrega.
    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
2026-09-16 Coloca os PDFs na raiz de 01-entregas e remove o Canvas antigo
    Quem abre a pasta quer o que foi entregue, então o PDF fica na raiz.
    Markdown e Word ficam em md/ e docx/.
    O Canvas-Projeto.docx era uma versão anterior do Canvas_Apresentacao_v1,
    sem a capa, o logo e as imagens. Só o entregue permanece.
    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
2026-09-16 Registra as decisões de 16/09: só simulação, Wokwi e calendário oficial
    O grupo não vai comprar a placa; não há tempo hábil até a entrega. A
    Waveshare ESP32-S3-SIM7670G fica como plataforma de referência e todo o
    desenvolvimento e os testes acontecem no Wokwi, que é o caminho previsto
    no item 4.2 do roteiro da disciplina. A seção 2.5 do Roteiro 2 passa a
    dizer isso, com a lista de materiais mantida como custo de referência.
    O calendário passa a ser o atualizado na Aula 04. O Markdown vira a fonte
    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
2026-09-16 Troca a licença MIT pela GNU GPL v3 e regera os PDFs das entregas
    O planejamento prometia MIT, mas o arquivo LICENSE nunca tinha entrado no repositório. Entra agora com a GPL v3, e a troca chega a todo lugar que citava a MIT: os roteiros em Markdown e Word, os dois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
    Os PDFs do Roteiro 1 e do Canvas v1 foram gerados de novo a partir do Word; a única diferença de texto em relação aos anteriores é a licença. O Canvas v2, apresentado em 16/09, entra pela primeira ve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
    [meuamparo_case.scad]
2026-09-24 Numera as entregas pela ordem e adiciona o resumo do EPEI
    PDFs, Markdown e Word de 01-entregas ganham o prefixo 01 a 05, na ordem em que
    foram entregues: Roteiro 1, Canvas, seminário de planejamento, resumo do III EPEI
    e Roteiro 2. Entram também os modelos do EPEI recebidos da disciplina.
2026-10-28 Implementa detecção de queda, botão de ajuda e alerta na simulação
    O core ganha o detector de queda em três fases (queda livre, impacto e
    imobilidade), o geofence com histerese, a máquina de estados do
    dispositivo com janela de cancelamento e o formato JSON do alerta. Tudo
    em C puro, com testes de host no make test.
    O firmware lê o MPU6050 por I2C, o botão, o LED e o buzzer, e usa o core
    como componente do ESP-IDF a partir dos mesmos fontes dos testes. O
    alerta sai no serial como MA_ALERT. A posição é fixa porque o Wokwi não
    tem GNSS.
    O diagrama do Wokwi recebe MPU6050, botão e buzzer, e make sim passa a
    rodar os cenários de queda, queda cancelada, pulo e botão. Os cenário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
